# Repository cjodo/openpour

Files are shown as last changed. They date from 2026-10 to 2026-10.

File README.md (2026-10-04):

# OpenPour

An open-source automatic pour-over machine. It has a 3D-printed body and
commodity parts from the 3D-printer aisle. It's controlled from any phone or
laptop browser, with no app store and no cloud.

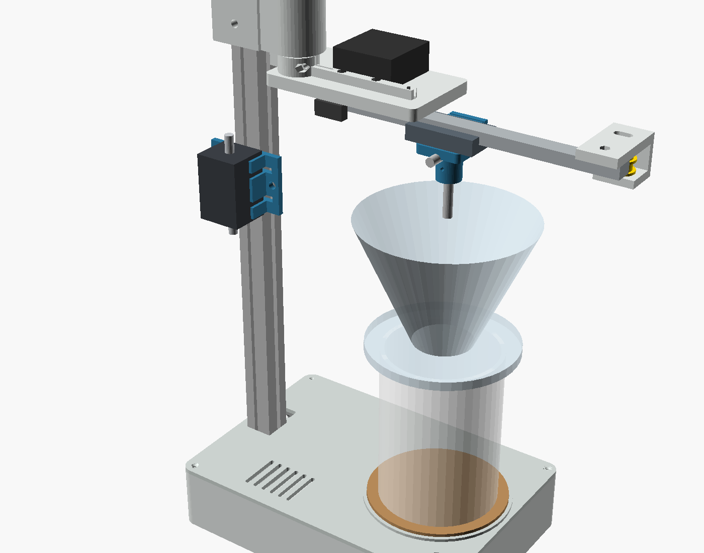
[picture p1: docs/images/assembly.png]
Assembly preview


- **Pours like a barista.** A two-axis polar arm traces centre, circle and
  spiral patterns over the dripper.
- **Pours by volume.** An inline flow meter counts every millilitre, and
  1 mL of water is 1 g, so each stage stops at its gram target whatever the
  pump does.
- **Configurable recipes.** Stages, water, flow rate, pattern, radius, speed
  and bloom/wait times are all editable in the app and stored on the machine.
- **Low voltage only.** You fill an insulated reservoir from your own
  kettle. The machine pumps, meters and measures temperature, but never
  heats water.
- **Parametric.** Set your cup and dripper heights in one OpenSCAD file and
  the column length, head position and parts follow.

## How it works

```
 reservoir ──tube──► peristaltic pump ──► flow meter ──► nozzle on carriage
 (hot water,                                  │            │  radial axis (belt, pancake NEMA17)
  DS18B20)                                    │   arm ─────┘  theta axis (direct-drive NEMA17)
                                              │    │
                                              │  dripper and cup on the base
                                              │
                ESP32 ◄────── pulses ─────────┘ ──Wi-Fi──► browser app (served by the ESP32)
```

The firmware converts each pattern from dripper-centred coordinates into arm
angle and carriage radius 100 times a second. Both steppers run in velocity
mode so the nozzle can follow spirals smoothly. The pump's speed is
feed-forward from its calibrated rate, trimmed by the measured flow, and cut
just early enough that the pump's coast-down lands on target.

## Repository

| Path | What |
|---|---|
| `hardware/cad/` | OpenSCAD model. `config.scad` holds every dimension; `make` exports STLs |
| `firmware/` | ESP32 firmware in Rust: `pourcore/` holds the hardware-independent logic, `esp32/` runs it on ESP-IDF, `sim/` runs it on a PC against simulated hardware |
| `web/` | The control app: TypeScript (`src/`) bundled with esbuild into `dist/`, which the firmware embeds at build time |
| `docs/` | [BOM](docs/BOM.md), [wiring](docs/wiring.md), [assembly](docs/assembly.md), [calibration](docs/calibration.md) |

## Build it

1. **Print.** In `hardware/cad`, edit `config.scad`, then run `make`, or
   open `openpour.scad` in OpenSCAD and choose a part. Print in PETG or ASA.
2. **Buy.** See the [bill of materials](docs/BOM.md). It comes to about
   US$170–210 (CA$240–300, €150–190).
3. **Wire.** See [wiring](docs/wiring.md).
4. **Flash.** Install [Node.js](https://nodejs.org) 18 or newer (the
   firmware build compiles the web app), and the Rust ESP32 toolchain once:
   ```sh
   cargo install espup ldproxy espflash
   espup install --targets esp32     # writes ~/export-esp.sh
   ```
   espflash 4.6 needs Rust 1.95 or newer; on an older Rust, install
   `espflash@4.5.0` instead.
   Then plug in the board and run:
   ```sh
   source ~/export-esp.sh
   cd firmware/esp32
   cargo run --release    # builds the web app and firmware, flashes, opens the monitor
   ```
   The first build downloads ESP-IDF, so it takes a while. The serial
   monitor shows the address to open. On Linux, add yourself to the group
   that owns `/dev/ttyUSB0` (`uucp` on Arch, `dialout` on Debian/Ubuntu).
5. **Calibrate.** Follow [calibration](docs/calibration.md). On first boot,
   join the `OpenPour-XXXX` Wi-Fi network (password `pourover`) and open
   http://192.168.4.1.

## Develop without hardware

### Host simulator (the real firmware logic)

`firmware/sim` runs the firmware's logic (`pourcore`: brewing, flow control,
motion, the flow meter, command handling) on your computer against simulated
hardware: stepper axes with endstop switches, a pump with ripple and
coast-down, and a flow meter whose real pulses-per-litre differs from the
default, so calibration matters as it does on a real machine. It serves the
built web app and the firmware's exact API.

```sh
cd web && npm ci && npm run watch      # rebuilds web/dist on save (or `npm run build` once)
cd firmware/sim && cargo run           # then open http://localhost:8080
```

- **Options:** `--speed 4` runs four times faster, `--lan` lets a phone on your
  network connect, and `--port`, `--data` and `--web` change the defaults.
  Settings and recipes persist in `firmware/sim/data/`.
- **Logging:** the firmware's log lines print in the terminal. Run with
  `RUST_LOG=debug` to also see the flow controller's internals.
- **`GET /api/sim`** shows what really happened, for example how much water
  reached the cup (`dispensedG`). Use it as the "real amount" when you
  calibrate the meter.
- **`POST /api/sim`** injects faults and drives the hardware, for example:

  ```sh
  curl -X POST localhost:8080/api/sim -d '{"faults":{"dry":true}}'
  ```

  - Faults: `dry`, `meterDead`, `radialEndstopStuck`, `thetaEndstopStuck`,
    `noProbe`.
  - Hardware: `trueGps` (pump rate), `truePpl` (meter pulses per litre),
    `tempC`, `{"press": "short"|"long"}` (the front button), and
    `{"resetDispensed": true}`.

### Wokwi (the real firmware on a simulated ESP32)

[Wokwi](https://wokwi.com) emulates the ESP32 itself, so it runs the actual
firmware image: ESP-IDF, Wi-Fi, the HTTP server and the drivers. Use it for
the code the host simulator can't reach. `firmware/wokwi/diagram.json` wires
up the board as `docs/wiring.md` describes, with two custom chips written in
Rust (`firmware/wokwi/chips`):

- **Pump + flow meter:** it reads the pump's PWM duty on GPIO 23 and sends
  pulses to GPIO 16 at a realistic rate.
- **Stepper axis + endstop** (one per axis): it counts STEP/DIR pulses and
  closes the endstop switch at the end of travel, so homing really runs.

Each chip has sliders for faults: dry pump, dead meter and a broken switch.
The DS18B20, the button and a pump LED are standard Wokwi parts.

```sh
firmware/wokwi/run.sh --timeout 60000     # builds if needed (--build to force), then runs wokwi-cli
```

`run.sh` takes the token from `WOKWI_CLI_TOKEN` or from `~/.wokwi/token` (a
bare token or a `NAME=token` line). It explains a missing or rejected token,
and passes any other options to `wokwi-cli`. `build.sh` builds the chips, the
firmware with `--features wokwi`, and a 4 MB flash image.

The `wokwi` feature makes the firmware join Wokwi's open `Wokwi-GUEST`
network instead of starting its own access point. In VS Code with the Wokwi
extension, open `firmware/wokwi/` and the web app is at
http://localhost:8180. The token is free from wokwi.com/dashboard/ci.

### Browser-only mock

```sh
cd web
npm ci
npm run dev
# open http://localhost:8000/?mock          (add &speed=4 to fast-forward)
```

`src/mock.ts` is a simplified machine written in TypeScript. It needs no Rust
toolchain, and edits to `src/` show up on reload. Because it's a separate
implementation, check behaviour against the host simulator. The protocol's
types live in `src/types.ts`. Before committing, run `npm run typecheck`
(`npm run build` also runs it). Neither simulator is part of the firmware
build.

## Firmware tests

Kinematics, pour patterns, flow control, flow-meter counting, motion control,
the brew state machine and command handling all live in `pourcore`, which
has no hardware dependencies. Its tests run on your computer, with a
simulated machine for the brew tests. The simulator's own tests brew through
the real homing sequence and flow meter, including fault cases:

```sh
cd firmware/pourcore && cargo test
cd firmware/sim && cargo test
```

## Recipe format

Recipes are stored on the machine as JSON. `water` is the amount added
in that stage, in grams.

```json
{
  "id": "v60-single",
  "name": "V60 single cup",
  "dose": 15,
  "minTemp": 92,
  "stages": [
    { "name": "Bloom", "water": 45, "flow": 4, "pattern": "spiral", "radius": 22, "rps": 1.2, "wait": 40 },
    { "name": "Pour 1", "water": 55, "flow": 4.5, "pattern": "spiral", "radius": 26, "rps": 1, "wait": 10 }
  ]
}
```

`pattern` is `center`, `circle` or `spiral`. `rps` is revolutions per
second around the dripper.

## API

| | |
|---|---|
| `GET /api/settings`, `POST /api/settings` | Machine settings (partial updates allowed) |
| `GET /api/recipes`, `POST /api/recipes` | The full recipe array |
| `ws://<host>/ws` | Status pushed 5× per second; send `{"cmd": "start", "recipe": "<id>"}`, `pause`, `resume`, `stop`, `home`, `park`, `center`, `jog`, `setCenter`, `release`, `prime`, `meterRun` (calibration dispense), `calMeter` (`{"ml": <measured>}`), `calPump` |

## Status

The firmware (Rust, on ESP-IDF) compiles and its core logic is unit-tested,
including simulated brews, but it hasn't run on real hardware yet. The app
runs against the simulator. The mechanical design is a first revision that hasn't
been printed yet. Expect to adjust clearances, switch positions and hole
sizes on the first build. Reports and fixes are welcome.

## Safety

Hot water burns. Keep the reservoir lid on and the machine on a stable
surface, and never run the pump without a cup under the nozzle. The firmware
stops if the flow meter sees no water, or if it counts more than the recipe
holds. It can't see what is in the cup, though, so it is not a substitute
for paying attention.

## License

MIT. See [LICENSE](LICENSE).

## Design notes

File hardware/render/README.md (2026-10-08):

# Renders

Scripts for picturing the assembled machine outside OpenSCAD. Generated files
go to `out/`, which git ignores. Add new render scripts here.

## The assembly as separate parts

```sh
hardware/render/export.sh                     # out/assembly/*.stl, ~15 s
hardware/render/export.sh -D 'arm_theta=-30' -D 'carriage_r=140' -o hardware/render/out/swung
```

This exports one STL per component, rendered in parallel. All the files
share the assembly's coordinates (millimetres, Z up), so they import already
in place, and each one can get its own material. Any `-D` option goes
straight to OpenSCAD:
- `arm_theta` (−78 to 25°) and `carriage_r` (66 to 175 mm) pose the arm;
- `show_cup=false` leaves out the mug and dripper;
- `$fn=128` gives rounder curves for close-ups.

The components are named by `component("...")` in
`hardware/cad/openpour.scad`. When you add a part to the assembly there, wrap
it the same way and add its name to the list in `export.sh`.

For a single merged STL instead (no separate materials, and touching parts
fuse together):

```sh
cd hardware/cad && openscad -D 'part="assembly"' -o assembly.stl openpour.scad
```

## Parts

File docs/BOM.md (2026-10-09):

# Bill of materials

Every purchased part is a commodity item from the 3D-printer, maker or
plumbing aisle. All of them are available from AliExpress, Amazon and most
maker shops. Prices are rough single-unit figures as a guide, not quotes.
CAD and EUR are converted from USD at 1 USD ≈ 1.42 CAD ≈ 0.89 EUR
(October 2026), so local prices and shipping will vary.

## Motion

| Qty | Part | Notes | ≈ USD | ≈ CAD | ≈ EUR |
|---|---|---|---|---|---|
| 1 | NEMA17 stepper, 40 mm body | Arm swing (theta), direct drive | 10 | 14 | 9 |
| 1 | NEMA17 "pancake" stepper, 20–23 mm body | Carriage (radial). Shaft ≥ 18 mm | 9 | 13 | 8 |
| 1 | MGN12H linear rail, 200 mm, with carriage | The arm itself | 12 | 17 | 11 |
| 1 | GT2 20T pulley, 5 mm bore, 6 mm belt | On the pancake motor, mounted hub-up | 1 | 1 | 1 |
| 1 | GT2 20T toothless idler, 5 mm bore | Arm tip | 1 | 1 | 1 |
| 1 | GT2 6 mm open belt, 1 m | ~520 mm used | 2 | 3 | 2 |
| 1 | Flexible shaft coupler, 5 mm to 8 mm | Theta motor to pivot shaft | 2 | 3 | 2 |
| 1 | 8 mm steel rod, 100 mm | Pivot shaft (linear rod offcut is fine) | 3 | 4 | 3 |
| 2 | 608ZZ bearing | Pivot | 1 | 1 | 1 |
| 1 | 8 mm shaft collar | Above the top bearing, carries the arm's weight | 1 | 1 | 1 |
| 1 | 2020 aluminium extrusion, 400 mm | Column. `column_len` in the CAD gives the exact length for your cups | 5 | 7 | 4 |
| 2 | Lever microswitch, KW11-3Z (20 × 10 mm) | Endstops | 1 | 1 | 1 |

## Water

| Qty | Part | Notes | ≈ USD | ≈ CAD | ≈ EUR |
|---|---|---|---|---|---|
| 1 | 12 V peristaltic pump, 300–400 mL/min | Kamoer KPHM400-style or equivalent. Peristaltic means only the tube touches water | 25–40 | 36–57 | 22–36 |
| 1.5 m | Food-grade silicone tubing to fit the pump, rated ≥ 100 °C | | 4 | 6 | 4 |
| 1 | ¼" (6 mm) 304 stainless 90° elbow hose barb | The nozzle. One leg is clamped vertically by the holder | 3 | 4 | 3 |
| 1 | Vacuum-insulated jug, 1–1.5 L, wide mouth | The reservoir. Fill it from your kettle | 15 | 21 | 13 |
| 1 | DS18B20 waterproof probe (stainless) + 4.7 kΩ resistor | Hangs in the reservoir | 2 | 3 | 2 |
| 1 | Hall-effect flow meter for hot drinks + 10 kΩ resistor | Measures the water, since 1 mL = 1 g. See below | 20–35 | 28–50 | 18–31 |
| 1 | Cork or silicone coaster, 95 mm | Sits in the lid's ring so hot cups never touch the print | 1 | 1 | 1 |

### Choosing the flow meter

The machine pours by volume, so the flow meter sets the accuracy.
- **Food-safe and rated for brewing-temperature water (≥ 90 °C).** Meters
  made for coffee machines, such as the Digmesa FHKSC family, are built for
  this.
- **Accurate from about 60 to 500 mL/min,** which covers recipes from 1 to
  8 g/s.
- **Pulse output with a known pulses-per-litre figure.** It's usually
  open-collector, powered from 5 V. The firmware's default is 1925 pulses/L;
  calibration measures yours.
- **Barbs that fit your tubing,** usually ¼" (6 mm).

Avoid the cheap YF-S401 / YF-S201 garden-style sensors. Most are rated to
about 80 °C, are not food-safe, and lose accuracy below about 300 mL/min.

## Electronics

| Qty | Part | Notes | ≈ USD | ≈ CAD | ≈ EUR |
|---|---|---|---|---|---|
| 1 | ESP32 DevKit V1 (ESP32-WROOM-32) | 30- or 38-pin. Not a WROVER board (GPIO 16) | 5 | 7 | 4 |
| 2 | TMC2209 StepStick driver | Standalone STEP/DIR, MS1 + MS2 high for 1/16 microstepping | 8 | 11 | 7 |
| 2 | StepStick carrier/expansion board | The small red boards with screw terminals and a 100 µF cap | 2 | 3 | 2 |
| 1 | Logic-level MOSFET module (AOD4184 / D4184 type) | Pump PWM | 1 | 1 | 1 |
| 1 | Schottky diode SS34 or 1N5819 | Across the pump motor (flyback) | 0.2 | 0.3 | 0.2 |
| 1 | Buck converter 12 V → 5 V (MP1584 or LM2596) | Powers the ESP32 via its 5 V/VIN pin | 1 | 1 | 1 |
| 1 | 12 V 5 A power supply, 5.5 × 2.1 mm plug | | 10 | 14 | 9 |
| 1 | Panel-mount DC jack, 5.5 × 2.1 mm (11–12 mm hole) | | 1 | 1 | 1 |
| 1 | 12 mm momentary push button | Start / pause / stop | 1 | 1 | 1 |
| 1 | 5 × 7 cm double-sided prototype board + female headers | Carries the ESP32 | 1 | 1 | 1 |
| – | Dupont/JST leads, 22 AWG wire for 12 V | | 3 | 4 | 3 |

## Fasteners

| Qty | Part | Where |
|---|---|---|
| ~30 | M3 screws 8–12 mm + nuts | Lid, rail, carriage, brackets, motors (from below through the motor plates) |
| 1 | M5 × 12 mm | Up through the base into the column (tap the extrusion's centre hole M5) |
| 4 | M5 × 10 mm + 4 drop-in T-nuts | Head clamp |
| 2 | M5 × 10 mm + 2 drop-in T-nuts | Pump bracket |
| 2 | M5 × 10 mm + 2 drop-in T-nuts | Flow meter clip |
| 2 | Cable ties, 3–4 mm wide | Flow meter to its clip |
| 1 | M5 × 40 mm + nut | Idler axle |
| 4 | 10 mm self-adhesive rubber feet | Base |

Expect about **US$185–235 / CA$260–330 / €165–210** total with the pump
and jug, less if you have printer leftovers. Filament for the printed parts
adds about US$11–15 / CA$16–21 / €10–13 (see [Filament](#filament)).

## Printed parts

Export with `make` in `hardware/cad` (or open `openpour.scad` and pick a
`part`). Print in PETG or ASA at 0.2 mm, 4 perimeters, 30 % infill.

| Part | Qty | ≈ g each | Orientation |
|---|---|---|---|
| base_tub | 1 | 245 | as exported (floor down) |
| base_lid | 1 | 120 | as exported |
| head | 1 | 80 | as exported (bearing pocket down) |
| arm_root | 1 | 50 | as exported (rail face down) |
| arm_tip | 1 | 12 | as exported |
| nozzle_holder | 1 | 12 | as exported. Supports under the belt clamp |
| switch_bracket | 2 | 2 | as exported |
| pump_bracket | 1 | 20 | as exported. Drill the slots to suit your pump |
| meter_clip | 1 | 12 | as exported (column plate down). Set `meter_body` in `config.scad` to your meter first |

### Filament

The parts weigh about **550 g** in PETG at the settings above. Allow about
**600 g** for supports, brims and purge, which is roughly 60 % of a 1 kg
spool. At US$18–25 per kg, the filament costs about
**US$11–15 / CA$16–21 / €10–13**. ASA weighs about 15 % less (it's less dense).

The weights are estimates from the CAD volumes, not slicer output, so your
slicer's figure may differ by 10–15 %. Most of the plastic is in the
thin-walled base tub and lid, which print nearly solid at any infill.

No printed part touches water or a hot cup. Water only touches the silicone
tube, the flow meter and the stainless nozzle, and the coaster isolates the
cup's heat.
PETG softens around 80 °C, which is why the coaster matters.

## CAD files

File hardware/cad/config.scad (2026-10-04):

// OpenPour: every dimension you might want to change lives here.
// Units: mm. Origin: the arm pivot axis at table level. +X points from the
// pivot to the dripper (towards the user), +Z is up.

/* [Your cups and dripper] */
cup_height = 110;        // tallest mug or server you'll brew into
dripper_height = 90;     // dripper body including its base
nozzle_clearance = 20;   // gap between dripper rim and nozzle tip

/* [Layout] */
dripper_offset = 110;    // pivot axis to dripper centre (firmware: centerR)
column_x = -35;          // 2020 column centre
base_back = -52;         // base rear edge
base_front = 163;        // base front edge
base_width = 150;

/* [Print settings] */
wall = 2.4;
clearance = 0.25;        // added to holes and sockets; raise for loose printers
$fn = 48;

/* [Base] */
floor_t = 3;
tub_height = 43;         // floor bottom to lid underside
lid_t = 3;
corner_boss_d = 9;
screw_m3_tap = 2.6;      // self-tapping into plastic; 4.0 for heat-set inserts
screw_m3_clear = 3.4;
screw_m4_clear = 4.4;
screw_m5_clear = 5.4;

/* [Cup rest] */
coaster_d = 95;              // cork/silicone coaster: printed parts must not touch hot cups
coaster_t = 4;
coaster_ring_h = 2;          // locating ring on the lid keeps the coaster under the dripper

/* [Flow meter: measure yours] */
meter_body = [45, 30, 28];   // length along the flow x width x height, without the barbs
meter_barb_len = 12;         // each end

/* [Column, 2020 extrusion] */
ext = 20;
column_socket_depth = 35;   // leaves solid plastic under the column for its M5 bolt

/* [Head: theta motor + pivot] */
nema = 42.3;
nema_hole_spacing = 31;
nema_boss_d = 22.5;          // flange pilot
coupler_d = 20;              // 5 mm to 8 mm flexible coupler
coupler_len = 25;
collar_t = 10;               // 8 mm shaft collar above the top bearing
bearing_od = 22;             // 608
bearing_t = 7;
head_h = 65;
head_gap = 2;                // between head and arm hub

/* [Arm] */
// Nothing on the arm may reach further than ~22 mm behind the pivot, or it
// hits the column when the arm swings.
shaft_d = 8;
hub_d = 26;
hub_h = 20;
finger_r = 21;               // theta endstop finger, points at the column at theta = 0
beam_t = 8;
beam_back = -15;
beam_front = 95;
beam_y = [-16, 46];          // beam spans the rail (y = 0) and the motor/belt side
rail_len = 200;
rail_start = 20;             // rail end nearest the pivot
rail_w = 12;
rail_h = 8;
rail_hole_pitch = 25;
rail_hole_first = 12.5;
radial_motor_x = 45;         // pancake NEMA17 on top of the beam, shaft down
radial_motor_len = 23;       // pancake NEMA17 body
radial_motor_pocket = 4;     // motor face sits this far into the beam (pulley mounted hub-up)
belt_y = 24;                 // belt loop centre line, beside the carriage
pulley_z = [-16, -2];        // pulley/idler band below the beam
pulley_pitch_r = 6.37;       // GT2 20T

/* [Carriage + nozzle (MGN12H)] */
carriage_w = 27;
carriage_len = 45.4;
carriage_h = 13;             // rail mount face to carriage face
carriage_hole_spacing = 20;  // 20 x 20 M3 pattern
nozzle_d = 8;                // leg of a 1/4" stainless elbow barb
nozzle_drop = 25;            // nozzle tip below the holder plate
holder_t = 6;

/* [Endstops: KW11-3Z style lever switch, 20 x 10 x 6.4] */
switch_hole_spacing = 9.5;
switch_hole_d = 2.2;

// ---------------------------------------------------------------- derived
lid_top = tub_height + lid_t;
cup_base_z = lid_top + coaster_t;
nozzle_tip_z = cup_base_z + cup_height + dripper_height + nozzle_clearance;
beam_bottom_z = nozzle_tip_z + nozzle_drop + holder_t + carriage_h;
head_bottom_z = beam_bottom_z + hub_h + head_gap;
head_top_z = head_bottom_z + head_h;
column_bottom_z = tub_height - column_socket_depth;
column_len = ceil((head_top_z - column_bottom_z) / 10) * 10;  // cut your 2020 to this

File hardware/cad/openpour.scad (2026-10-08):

// OpenPour: open the file in OpenSCAD for the assembly preview, or export one
// print-ready part at a time:
//   openscad -D 'part="head"' -o stl/head.stl openpour.scad
// (`make` in this folder exports all of them.)

include <config.scad>
use <vitamins.scad>
include <parts.scad>

/* [View] */
part = "assembly";  // [assembly, base_tub, base_lid, head, arm_root, arm_tip, nozzle_holder, switch_bracket, pump_bracket, meter_clip]
arm_theta = 0;      // [-78:1:25]
carriage_r = 110;   // [66:1:175]
show_cup = true;
component = "all";  // one piece of the assembly, for hardware/render/export.sh

echo(str("Cut the 2020 column to ", column_len, " mm. Nozzle tip at ", nozzle_tip_z, " mm above the table."));

if (part == "assembly") assembly();
else print_part(part);

module print_part(name) {
  if (name == "base_tub") base_tub();
  if (name == "base_lid") translate([0, 0, -tub_height]) base_lid();
  if (name == "head") translate([0, 0, -head_bottom_z]) head();
  if (name == "arm_root") arm_root();
  if (name == "arm_tip") translate([0, 0, 6]) rotate([180, 0, 0]) arm_tip();
  if (name == "nozzle_holder")
    translate([0, 0, carriage_h + holder_t]) nozzle_holder();
  if (name == "switch_bracket") switch_bracket();
  if (name == "pump_bracket") pump_bracket();
  if (name == "meter_clip") rotate([90, 0, 0]) meter_clip();  // plate on the bed
}

// Renders its children only when `component` selects them (or is "all"), so
// hardware/render/export.sh can export the assembly one piece at a time.
module component(name) {
  if (component == "all" || component == name) children();
}

module arm_assembly() {
  component("arm") color("#e2e6e4") arm_root();
  component("arm") color("#e2e6e4") arm_tip();
  component("rail") translate([0, 0, -rail_h]) translate([rail_start, 0, 0]) mgn12_rail(rail_len);
  // face down in its pocket, shaft through the beam
  component("motor_radial")
    translate([radial_motor_x, belt_y, beam_t - radial_motor_pocket]) mirror([0, 0, 1]) nema17(radial_motor_len, 20);
  component("pulleys") {
    translate([radial_motor_x, belt_y, pulley_z[0]]) gt2_pulley();
    translate([rail_start + rail_len - 12, belt_y, pulley_z[0]]) gt2_pulley();
  }
  translate([carriage_r, 0, 0]) {
    component("carriage") translate([0, 0, -carriage_h]) mgn12h_carriage();
    component("nozzle_holder") color("#2e7da6") nozzle_holder();
    component("nozzle") translate([0, 0, -carriage_h - holder_t]) elbow_barb(nozzle_drop + 18);
  }
  component("switch") color("#444") translate([radial_switch_screws[0] - 6, -14, -12]) cube([20, 6.4, 10]);
}

module assembly() {
  component("base_tub") color("#e2e6e4") base_tub();
  component("base_lid") color("#cfd6d3") base_lid();
  component("coaster") translate([dripper_offset, 0, lid_top]) coaster(coaster_d, coaster_t);

  component("column") translate([column_x, 0, column_bottom_z]) ext2020(column_len);
  // flow meter on the column's side face, between the pump and the nozzle
  meter_z = head_bottom_z - 110;  // well below the arm and its pulleys
  translate([column_x, -ext / 2, meter_z]) rotate([0, 0, 180]) translate([-(meter_body[1] + 2 * wall + 20) / 2, 0, 0]) {
    component("meter_clip") color("#2e7da6") meter_clip();
    component("flow_meter") translate([10 + wall + meter_body[1] / 2, 4 + meter_body[2] / 2, 20 - meter_body[0] / 2])
      rotate([0, 0, 90]) rotate([0, -90, 0]) flow_meter(meter_body, meter_barb_len);
  }
  component("head") color("#e2e6e4") head();
  component("motor_theta") translate([0, 0, head_top_z]) mirror([0, 0, 1]) nema17();  // face down on the head
  component("bearings") for (z = [head_top_z - coupler_len - collar_t - 3 - bearing_t, head_bottom_z])
    translate([0, 0, z]) bearing608();
  component("shaft") color("silver") translate([0, 0, beam_bottom_z])
    cylinder(d = shaft_d, h = head_top_z - coupler_len / 2 - beam_bottom_z);

  translate([0, 0, beam_bottom_z]) rotate(arm_theta) arm_assembly();

  if (show_cup) translate([dripper_offset, 0, cup_base_z]) {
    component("mug") mug(cup_height);
    component("dripper") translate([0, 0, cup_height]) dripper(dripper_height);
  }
}

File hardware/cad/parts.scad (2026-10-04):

// Printed parts. Modules are drawn in assembly position; openpour.scad
// re-orients each one for printing.
//
// Arm parts use arm-local coordinates: origin on the pivot axis at the
// underside of the beam (where the rail mounts), +X along the arm.

include <config.scad>

e = 0.01;
C = clearance;

module rounded_box(size, r) {
  hull() for (x = [r, size[0] - r], y = [r, size[1] - r])
    translate([x, y, 0]) cylinder(r = r, h = size[2]);
}

module counterbored(d, head_d, head_h, len) {
  // hole along +Z from z=0, head recess at the bottom
  translate([0, 0, -e]) cylinder(d = d, h = len + 2 * e);
  translate([0, 0, -e]) cylinder(d = head_d, h = head_h + e);
}

// ------------------------------------------------------------------ base

base_len = base_front - base_back;
corner_inset = 6.5;
function corner_positions() = [
  for (x = [base_back + corner_inset, base_front - corner_inset],
       y = [-base_width / 2 + corner_inset, base_width / 2 - corner_inset]) [x, y]
];

// 50 x 70 mm double-sided prototype board for the ESP32 (M2 holes).
proto_board_origin = [-17, -35];
proto_board_holes = [[2, 2], [46 + 2, 2], [2, 66 + 2], [46 + 2, 66 + 2]];
button_pos = [base_front - 18, -base_width / 2 + 18];

module base_tub() {
  sock = ext + 10;
  difference() {
    union() {
      difference() {
        translate([base_back, -base_width / 2, 0]) rounded_box([base_len, base_width, tub_height], 8);
        translate([base_back + wall, -base_width / 2 + wall, floor_t])
          rounded_box([base_len - 2 * wall, base_width - 2 * wall, tub_height], 8 - wall);
      }
      for (p = corner_positions()) translate(p) cylinder(d = corner_boss_d, h = tub_height);
      // column socket
      translate([column_x - sock / 2, -sock / 2, 0]) cube([sock, sock, tub_height]);
      // proto board standoffs
      for (h = proto_board_holes) translate(proto_board_origin + h) cylinder(d = 6, h = floor_t + 5);
    }
    for (p = corner_positions()) translate([p[0], p[1], floor_t]) cylinder(d = screw_m3_tap, h = tub_height);
    // column pocket + M5 bolt up into the tapped extrusion end
    translate([column_x - ext / 2 - C, -ext / 2 - C, column_bottom_z]) cube([ext + 2 * C, ext + 2 * C, tub_height]);
    translate([column_x, 0, 0]) counterbored(screw_m5_clear, 10, 4, column_bottom_z);
    for (h = proto_board_holes) translate([proto_board_origin[0] + h[0], proto_board_origin[1] + h[1], 1]) cylinder(d = 1.7, h = 10);
    // rear wall: DC barrel jack (panel mount) and ESP32 USB access
    translate([base_back - 1, 40, 20]) rotate([0, 90, 0]) cylinder(d = 11.5 + C, h = wall + 2);
    translate([base_back - 1, -12, floor_t + 6]) cube([wall + 2, 14, 9]);
    // rubber foot recesses
    for (p = corner_positions()) translate([p[0], p[1], -e]) cylinder(d = 10.5, h = 1);
  }
}

module base_lid() {
  difference() {
    union() {
      translate([base_back, -base_width / 2, tub_height]) rounded_box([base_len, base_width, lid_t], 8);
      // coaster locating ring, centred under the dripper
      translate([dripper_offset, 0, lid_top - e]) difference() {
        cylinder(d = coaster_d + 2 * C + 2 * wall, h = coaster_ring_h + e);
        translate([0, 0, -1]) cylinder(d = coaster_d + 2 * C, h = coaster_ring_h + 2);
      }
    }
    for (p = corner_positions()) translate([p[0], p[1], tub_height - e]) {
      cylinder(d = screw_m3_clear, h = lid_t + 1);
      translate([0, 0, lid_t - 1.8]) cylinder(d1 = screw_m3_clear, d2 = 6.5, h = 1.8 + e);
    }
    translate([column_x - ext / 2 - C, -ext / 2 - C, tub_height - 1]) cube([ext + 2 * C, ext + 2 * C, lid_t + 2]);
    // momentary button (12 mm)
    translate([button_pos[0], button_pos[1], tub_height - 1]) cylinder(d = 12 + C, h = lid_t + 2);
    // cable pass-through beside the column: motors, endstops, pump, probe, flow meter
    translate([column_x - 8, ext / 2 + 5, tub_height - 1]) rounded_box([16, 10, lid_t + 2], 2);
    // vents over the stepper drivers
    for (i = [0 : 5]) translate([-5 + i * 7, -base_width / 2 + 12, tub_height - 1]) rounded_box([3, 30, lid_t + 2], 1.4);
  }
}

// ------------------------------------------------------------------ head

head_r = bearing_od / 2 + 6;

module head() {
  hb = head_bottom_z;
  ht = head_top_z;
  blk = ext + 16;
  cavity = coupler_len + collar_t + 3;
  difference() {
    union() {
      translate([column_x - blk / 2, -blk / 2, hb]) cube([blk, blk, head_h]);
      hull() {
        translate([column_x, -14, hb]) cube([e, 28, head_h]);
        translate([0, 0, hb]) cylinder(r = head_r, h = head_h);
      }
      translate([-nema / 2, -nema / 2, ht - 6]) cube([nema, nema, 6]);
    }
    // column bore and clamp screws into T-nuts on both side slots
    translate([column_x - ext / 2 - C, -ext / 2 - C, hb - 1]) cube([ext + 2 * C, ext + 2 * C, head_h + 2]);
    for (z = [hb + 14, ht - 14], s = [-1, 1])
      translate([column_x, s * (ext / 2 + 8 + 1), z]) rotate([90, 0, 0]) {
        cylinder(d = screw_m5_clear, h = 20, center = true);
        translate([0, 0, s > 0 ? -12 : 4]) cylinder(d = 10, h = 8);
      }
    // motor: pilot, coupler + collar cavity, 4 screws from below
    translate([0, 0, ht - cavity]) cylinder(d = coupler_d + 4, h = cavity + 1);
    for (x = [-1, 1], y = [-1, 1]) translate([x * nema_hole_spacing / 2, y * nema_hole_spacing / 2, ht - 7])
      cylinder(d = screw_m3_clear, h = 8);
    // bearings: top one under the cavity, bottom one from below
    translate([0, 0, ht - cavity - bearing_t]) cylinder(d = bearing_od + C, h = bearing_t + e);
    translate([0, 0, hb - e]) cylinder(d = bearing_od + C, h = bearing_t + e);
    translate([0, 0, hb]) cylinder(d = 16, h = head_h);
    // theta switch mount (two M3 pilots on the underside)
    for (p = theta_switch_mount_holes()) translate([p[0], p[1], hb - e]) cylinder(d = screw_m3_tap, h = 10);
  }
}

// The finger on the hub sweeps a circle of radius finger_r. The switch sits on
// that circle where the finger arrives at theta = thetaHomeDeg.
theta_home = -75;
function theta_switch_angle() = 180 + theta_home - 8;
function theta_switch_mount_holes() = [
  for (a = [theta_switch_angle() - 14, theta_switch_angle() + 2]) [ (head_r - 3) * cos(a), (head_r - 3) * sin(a) ]
];

// ------------------------------------------------------------------ arm

// The belt clamp must stay clear of the radial pulley, so the carriage homes
// at r ~ 66 mm (firmware radialHomeMm) against a switch under the beam.
radial_switch_screws = [28, 38];

function rail_holes() = [for (x = [rail_hole_first : rail_hole_pitch : rail_len]) rail_start + x];

module arm_root() {
  beam_y_len = beam_y[1] - beam_y[0];
  difference() {
    union() {
      translate([beam_back, beam_y[0], 0]) rounded_box([beam_front - beam_back, beam_y_len, beam_t], 4);
      cylinder(d = hub_d, h = hub_h);
      // endstop finger, pointing back at the column when theta = 0
      hull() {
        translate([-hub_d / 2 + 2, -3, beam_t]) cube([1, 6, hub_h - beam_t - 4]);
        translate([-finger_r, -2, beam_t]) cube([2, 4, hub_h - beam_t - 4]);
      }
      // stiffening rib along the rail line
      translate([hub_d / 2 - 2, -4, beam_t - e]) cube([beam_front - hub_d / 2 - 2 - 6, 6, 6]);
    }
    // shaft bore + clamp slit + clamp screw
    translate([0, 0, -1]) cylinder(d = shaft_d + C, h = hub_h + 2);
    translate([0, -0.75, beam_t]) cube([hub_d, 1.5, hub_h]);
    translate([hub_d / 2 - 4, 0, beam_t + (hub_h - beam_t) / 2]) rotate([90, 0, 0]) {
      cylinder(d = screw_m3_clear, h = hub_d, center = true);
      translate([0, 0, 5]) cylinder(d = 6.4, h = 10, $fn = 6);
    }
    // rail screws from below into nuts on top
    for (x = rail_holes()) if (x < beam_front - 4) translate([x, 0, -e]) {
      cylinder(d = screw_m3_clear, h = beam_t + 10);
      translate([0, 0, beam_t - 2.5]) cylinder(d = 6.4, h = 10, $fn = 6);
    }
    // radial motor: pocket, shaft, pilot, screws
    translate([radial_motor_x, belt_y, 0]) {
      translate([-nema / 2 - C, -nema / 2 - C, beam_t - radial_motor_pocket]) cube([nema + 2 * C, nema + 2 * C, 20]);
      translate([0, 0, -1]) cylinder(d = nema_boss_d + 1, h = beam_t + 2);
      for (x = [-1, 1], y = [-1, 1]) translate([x * nema_hole_spacing / 2, y * nema_hole_spacing / 2, -1]) {
        cylinder(d = screw_m3_clear, h = beam_t + 2);
        translate([0, 0, -e]) cylinder(d = 6, h = 1 + 1.5);
      }
    }
    // radial endstop bracket screws
    for (x = radial_switch_screws) translate([x, -12, -e]) cylinder(d = screw_m3_tap, h = 6);
  }
}
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

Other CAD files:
hardware/cad/vitamins.scad

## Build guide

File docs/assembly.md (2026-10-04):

# Assembly

Assembly preview

Before you start, set your cup and dripper heights in
`hardware/cad/config.scad`. `column_len` (printed in the OpenSCAD console as
a derived value) is the length to cut the 2020 extrusion to. A 400 mm stock
length covers mugs up to ~120 mm under a V60.

## Base

1. Press rubber feet into the four recesses under `base_tub`.
2. Tap the 2020 extrusion's centre hole M5 at one end. Push it into the
   socket and bolt it from underneath with an M5 × 12.
3. Fit the ESP32 prototype board on the standoffs, the stepper carriers on
   either side, and the MOSFET module and buck converter in front of them.
   Fix them with double-sided foam tape. Fit the DC jack to the rear wall.
   See [wiring.md](wiring.md).
4. Fit the button to the lid, route the cable bundle through the slot beside
   the column, and screw the lid on (4 × M3, countersunk).
5. Drop the coaster into the ring on the lid.

## Head and arm

1. Press the two 608 bearings into the head: one from below, and one into
   the pocket under the coupler cavity.
2. Bolt the 40 mm NEMA17 face-down on top of the head (4 × M3 from below).
   Fit the coupler on its shaft.
3. Slide the 8 mm shaft up through both bearings into the coupler. Put the
   collar on the shaft above the top bearing first, then tighten the
   coupler. The collar takes the arm's weight. Snug it so the shaft has no
   end-play but still turns freely.
4. Slide the head down the column on four T-nuts. Set its height so the
   nozzle ends up ~20 mm above your dripper rim, then tighten.
5. Fix the rail to the underside of `arm_root` (M3 up through the rail into
   nuts in the hex traps). Bolt `arm_tip` to the last rail hole.
6. Bolt the pancake motor into its pocket and fit the GT2 pulley hub-up
   below the beam. Fit the idler in the arm tip slot on an M5 × 40.
7. Clamp the arm's hub onto the shaft below the head with the M3 clamp
   screw.
8. Bolt `nozzle_holder` under the carriage (4 × M3). Loop the belt around
   the pulley and idler, tuck both ends into the holder's slot, pinch them
   with the M3, and tension by sliding the idler.
9. Fit one `switch_bracket` under the beam (radial endstop) so the carriage
   presses the lever about 23 mm before its centre reaches 66 mm from the
   pivot. Fit the other under the head (theta endstop) so the hub's finger
   presses it as the arm swings to about −75°. Fine-tune the exact numbers
   with **Arm angle at endstop** and **Carriage radius at endstop** in
   Advanced settings.

## Water

1. Bolt the pump bracket to the column with two T-nuts, then fit the pump.
2. Bolt `meter_clip` to the column's side face, above the pump and well below
   the arm, with two T-nuts. Cable-tie the flow meter into it with its barbs
   vertical and its arrow pointing **up**. Water flowing upward through the
   meter pushes the air out, so it stays full and counts accurately.
3. Push the stainless elbow's vertical leg into the nozzle holder so it pokes
   out ~25 mm below, then pinch it.
4. Run silicone tube from the bottom of the reservoir (weight the end with a
   stainless washer) through the pump, up through the meter, and on to the
   elbow. Keep the tube after the meter short. Leave a loose loop at the arm
   so it can swing.
5. Hang the DS18B20 probe in the reservoir.

Then work through [calibration.md](calibration.md).

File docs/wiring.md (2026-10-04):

# Wiring

Everything runs at 12 V or below. There is no mains voltage inside the
machine. The power brick is the only mains part, and it is off-the-shelf.

## Power

```
12 V brick ── DC jack ──┬── stepper carrier (theta)  VMOT
                        ├── stepper carrier (radial) VMOT
                        ├── pump (+) ──── pump (−) ── MOSFET module OUT−
                        │                 (SS34 across the pump, stripe to +)
                        ├── MOSFET module VIN+
                        └── buck converter IN ── 5 V OUT ── ESP32 5V/VIN
GND is common to everything, including the ESP32.
```

Set the buck converter to 5.0 V **before** connecting the ESP32.

## ESP32 pin map

The pin map is defined at the top of `firmware/esp32/src/main.rs`.

| ESP32 GPIO | Connects to | Notes |
|---|---|---|
| 26 | Theta driver STEP | |
| 25 | Theta driver DIR | |
| 33 | Radial driver STEP | |
| 32 | Radial driver DIR | |
| 27 | Both drivers EN | Active low, shared |
| 18 | Theta endstop | Switch COM to GND, NO to the pin (internal pull-up) |
| 19 | Radial endstop | Switch COM to GND, NO to the pin |
| 16 | Flow meter pulse output | 10 kΩ from the pin to 3V3. WROOM modules only, since WROVER uses 16 for PSRAM |
| 23 | MOSFET module PWM/SIG | |
| 4 | DS18B20 data | 4.7 kΩ from data to 3V3 |
| 13 | Push button | Other leg to GND |
| 2 | On-board LED | Status |

Power the DS18B20 from **3V3**, not 5 V, so its output is safe for the
ESP32. The flow meter can run from 5 V because its output is open-collector.
Pull that output up to **3V3 only**. If your meter has its own pull-up to its
supply, power it from 3V3 if the datasheet allows, or add a divider
(10 kΩ / 20 kΩ) so the pin never sees 5 V.

## Stepper drivers (TMC2209, standalone)

- Microstepping: MS1 **high**, MS2 **high** gives 1/16, which the firmware
  defaults assume. On carrier boards with three DIP switches, MS3 has no
  effect on a TMC2209, but check your driver's pinout. Some variants route
  PDN/UART to that pin.
- Motor current: set Vref for about 0.6 A RMS on the 40 mm motor and 0.4 A on the
  pancake. Most TMC2209 StepSticks use Vref ≈ I<sub>RMS</sub> × 1.41, but
  confirm against your board's documentation.
- Pair motor coils with a multimeter (continuity within a coil). If an axis
  runs backwards, tick **Reverse … direction** in the app's Advanced settings
  instead of rewiring.

## Flow meter

| Meter wire (typical) | Connects to |
|---|---|
| Red | 5 V |
| Black | GND |
| White, yellow or blue (signal) | GPIO 16, with 10 kΩ to 3V3 |

Wire colours vary, so check your meter's datasheet. The meter goes in the
tube between the pump and the nozzle, with its arrow pointing in the
direction of flow.

## Cable routing

Motor, endstop, pump, probe and flow meter cables leave the base through the slot beside
the column. Bundle them up the column with spiral wrap and leave a loose loop
to the arm so it can swing from −78° to +25°. The pump tube follows the same
path, through the flow meter, to the nozzle elbow.

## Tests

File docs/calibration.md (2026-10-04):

# First run and calibration

Everything here is done from the **Machine** tab of the app. Values are saved
on the machine and survive firmware updates.

## 1. Connect

On first boot the machine starts its own Wi-Fi network, **OpenPour-XXXX**,
with the password `pourover`. Join it and open http://192.168.4.1. Under
**Wi-Fi**, enter your home network and save. The machine restarts and is
then reachable at http://openpour.local. On some Android devices `.local`
names don't resolve, so use the IP address shown in the serial monitor or
your router's client list.

Add the page to your home screen to use it like an app.

## 2. Check directions and endstops

1. Press **Home**. The carriage should travel toward the pivot and stop on
   its switch, then the arm should swing toward its switch.
   - If an axis moves the wrong way, press **Motors off**, open
     **Advanced**, tick the matching **Reverse … direction** box, save, and
     home again.
   - If a switch never triggers, homing stops after 20 s with an error.
2. The arm then parks out of the way of the dripper.

## 3. Set the dripper centre

Put your cup and dripper on the coaster. Press **Go to centre**, then use the jog
pad until the nozzle sits over the middle of the dripper. Use **Fine** for
the last millimetres. Press **Save as centre**. Every pour pattern is drawn
around this point, so it absorbs any slop in the printed parts.

## 4. Prime

Fill the reservoir with hot water and put a cup under the nozzle. Press
**Prime 3 s** a few times until water flows steadily from the nozzle, with
no air bubbles in the tube.

The machine measures water as it passes the flow meter, so the tube between
the meter and the nozzle must already be full. Prime again whenever the
tube has drained, for example after refilling an empty reservoir.

## 5. Calibrate the flow meter

The meter's datasheet value is only a starting point. Each meter, and how
it's mounted, varies by a few percent.

1. Put an empty jug, or a mug on a kitchen scale (tared), under the nozzle.
2. Press **Dispense ~200 ml**. The machine homes, centres, and pumps until
   the meter has counted about 200 ml.
3. Measure what came out. On a kitchen scale, 1 g = 1 ml. Enter it under
   **Real amount** and press **Calibrate meter**.

Repeat once to check. The counted and real amounts should now agree to
within a couple of percent. Use hot water, as it would be when brewing.

## 6. Calibrate the pump

Empty the cup, put it back under the nozzle and press **Calibrate pump**.
The machine runs the pump flat out for 10 s and stores the rate the meter
measured. That rate is used to plan every pour.

## 7. Brew

On the **Brew** tab, choose a recipe and press **Start brew**, or press the
button on the base to brew the last recipe again. A short press pauses or
resumes, and a long press stops.

## Tuning notes

| Symptom | Setting (Advanced) |
|---|---|
| Overshoots each stage target | Raise **Pour stop lead time** |
| Stops short of each target | Lower **Pour stop lead time** |
| Cup holds more or less than the recipe | Re-run the flow meter calibration, and prime first |
| Pump stalls at slow flow rates | Raise **Pump minimum power** |
| Pattern looks small or large | Re-check **Carriage steps per mm** (80 for GT2 20T at 1/16) |
| Arm hits something at the end of travel | Narrow the arm/carriage min/max limits |

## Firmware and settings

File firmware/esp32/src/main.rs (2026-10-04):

//! OpenPour firmware: automated pour-over on an ESP32.
//! See ../../README.md for the hardware and ../../docs for wiring and
//! calibration. The machine logic lives in ../pourcore; this crate connects
//! it to the hardware.
//!
//! Pins (ESP32 DevKit V1, ESP32-WROOM-32; see docs/wiring.md). GPIO 16 is
//! free on WROOM modules; on WROVER (PSRAM) boards move the flow meter.
//!   theta stepper   STEP 26, DIR 25
//!   radial stepper  STEP 33, DIR 32
//!   stepper enable  27 (shared by both drivers, active low)
//!   endstops        theta 18, radial 19 (normally open to GND)
//!   flow meter      16 (pulse output, pulled up to 3V3)
//!   pump PWM        23 (gate of the MOSFET module)
//!   DS18B20         4 (4.7 kΩ pull-up to 3V3)
//!   button          13 (momentary to GND)
//!   status LED      2 (on-board)

mod ds18b20;
mod flowmeter;
mod net;
mod pump;
mod stepper;
mod storage;
mod web;

use esp_idf_svc::eventloop::EspSystemEventLoop;
use esp_idf_svc::hal::delay::FreeRtos;
use esp_idf_svc::hal::gpio::{Input, PinDriver, Pull};
use esp_idf_svc::hal::ledc::{config::TimerConfig, LedcDriver, LedcTimerDriver, Resolution};
use esp_idf_svc::hal::peripherals::Peripherals;
use esp_idf_svc::hal::reset;
use esp_idf_svc::hal::units::Hertz;
use esp_idf_svc::log::EspLogger;
use esp_idf_svc::nvs::EspDefaultNvsPartition;
use esp_idf_svc::sys::esp_timer_get_time;
use pourcore::app::{self, Button, Effect};
use pourcore::brew::Brew;
use pourcore::machine::{Machine, MotionCmd};
use pourcore::meter::FlowMeter;
use pourcore::motion::{Endstops, Motion};
use pourcore::nozzle;
use pourcore::recipes::{self, Recipe};
use pourcore::settings::Settings;
use serde_json::Value;

use crate::ds18b20::Ds18b20;
use crate::flowmeter::PulseCounter;
use crate::net::Net;
use crate::pump::Pump;
use crate::stepper::Stepper;

const STATUS_PERIOD_MS: u32 = 100;
const REBOOT_DELAY_MS: u32 = 1500;
/// A loop iteration longer than this is logged: it delays motion and flow control.
const LOOP_STALL_MS: u32 = 50;

fn millis() -> u32 {
    (unsafe { esp_timer_get_time() } / 1000) as u32
}

type Enable = Box<dyn FnMut(bool)>;

/// Every device behind the brew logic.
struct Devices {
    settings: Settings,
    net: Net,
    pulses: PulseCounter<'static>,
    meter: FlowMeter,
    thermo: Ds18b20<'static>,
    pump: Pump<'static>,
    motion: Motion<Stepper, Enable>,
    theta_endstop: PinDriver<'static, Input>,
    radial_endstop: PinDriver<'static, Input>,
}

impl Devices {
    fn update(&mut self, now: u32) {
        self.meter.on_count(self.pulses.total(), now, self.settings.flow_pulses_per_litre);
        self.thermo.update(now);
        self.pump.update(now);
        let end = Endstops { radial: self.radial_endstop.is_low(), theta: self.theta_endstop.is_low() };
        self.motion.update(now, &self.settings, end);
    }
}

impl Machine for Devices {
    fn now_ms(&self) -> u32 {
        millis()
    }

    fn settings(&self) -> &Settings {
        &self.settings
    }

    fn settings_mut(&mut self) -> &mut Settings {
        &mut self.settings
    }

    fn save_settings(&mut self) {
        stepper::set_inverted(self.settings.invert_theta, self.settings.invert_radial);
        if !storage::save_settings(&self.settings) {
            log::error!("could not save settings");
        }
        self.net.publish_settings(&self.settings);
    }

    fn load_recipe(&mut self, id: &str) -> Option<Recipe> {
        recipes::find(&storage::read_recipes()?, id)
    }

    fn first_recipe_id(&mut self) -> Option<String> {
        recipes::first_id(&storage::read_recipes()?)
    }

    fn save_recipes(&mut self, r: &Value) -> bool {
        storage::save_recipes(r)
    }

    fn grams(&self) -> f32 {
        self.meter.grams()
    }

    fn flow_gps(&self) -> f32 {
        self.meter.flow_gps()
    }

    fn flow_valid(&self) -> bool {
        self.meter.flow_valid()
    }

    fn meter_pulses(&self) -> u32 {
        self.meter.pulses()
    }

    fn reset_poured(&mut self) {
        self.meter.reset();
    }

    fn temp_c(&self) -> Option<f32> {
        self.thermo.celsius()
    }

    fn pump_set(&mut self, duty: f32) {
        self.pump.set(duty);
    }

    fn pump_run_for(&mut self, duty: f32, ms: u32) {
        self.pump.run_for(duty, ms, millis());
    }

    fn pump_duty(&self) -> f32 {
        self.pump.duty()
    }

    fn motion(&mut self, cmd: MotionCmd) {
        let s = &self.settings;
        let m = &mut self.motion;
        match cmd {
            MotionCmd::Home => m.home(millis(), s),
            MotionCmd::Hold => m.hold(s),
            MotionCmd::Park => m.park(s),
            MotionCmd::MoveToBed(p) => m.move_to_bed(p, s),
            MotionCmd::Follow(p) => m.follow(p, millis()),
            MotionCmd::Jog { dr, dtheta } => m.jog(dr, dtheta, s),
            MotionCmd::Release => m.release(),
            MotionCmd::SetCentreHere => {
                let p = m.centre_here(s);
                self.settings.center_r = p.r;
                self.settings.center_theta_deg = p.theta_deg;
                self.save_settings();
            }
        }
    }

    fn homed(&self) -> bool {
        self.motion.homed()
    }

    fn homing_failed(&self) -> bool {
        self.motion.homing_failed()
    }

    fn motion_busy(&self) -> bool {
        self.motion.busy(&self.settings)
    }

    fn motion_mode(&self) -> &'static str {
        self.motion.mode_name(&self.settings)
    }

    fn arm_pose(&self) -> (f32, f32) {
        let p = self.motion.pose(&self.settings);
        (p.theta_deg, p.r)
    }

    fn ap_mode(&self) -> bool {
        self.net.ap_mode()
    }
}

fn main() -> anyhow::Result<()> {
    esp_idf_svc::sys::link_patches();
    EspLogger::initialize_default();

    let p = Peripherals::take()?;
    let pins = p.pins;

    // Pump off before anything else.
    let ledc_timer = LedcTimerDriver::new(
        p.ledc.timer0,
        &TimerConfig::new().frequency(Hertz(5000)).resolution(Resolution::Bits10),
    )?;
    let pump = Pump::new(LedcDriver::new(p.ledc.channel0, ledc_timer, pins.gpio23)?);

    let button = PinDriver::input(pins.gpio13, Pull::Up)?;
    let mut led = PinDriver::output(pins.gpio2)?;

    if let Err(e) = storage::mount() {
        log::error!("LittleFS mount failed: {e}");
    }
    #[allow(unused_mut)]
    let mut settings = storage::load_settings();
    #[cfg(feature = "wokwi")]
    if settings.wifi_ssid.is_empty() {
        log::info!("Wokwi build: joining Wokwi-GUEST");
        settings.wifi_ssid = "Wokwi-GUEST".into();
    }
    // Wokwi builds put a short test recipe first, so a full brew fits a test run.
    #[cfg(feature = "wokwi")]
    storage::ensure_default_recipes(include_str!("../../wokwi/recipes.json"));
    #[cfg(not(feature = "wokwi"))]
    storage::ensure_default_recipes(web::DEFAULT_RECIPES_JSON);

    let pulses = PulseCounter::new(pins.gpio16)?;
    let thermo = Ds18b20::new(PinDriver::input_output_od(pins.gpio4, Pull::Floating)?, millis());

    let (theta, radial) = stepper::start(
        (pins.gpio26, pins.gpio25, settings.invert_theta),
        (pins.gpio33, pins.gpio32, settings.invert_radial),
    )?;
    let mut enable_pin = PinDriver::output(pins.gpio27)?;
    let enable: Enable = Box::new(move |on| {
        let _ = enable_pin.set_level((!on).into()); // active low
    });
    let motion = Motion::new(theta, radial, enable, &settings);
    let theta_endstop = PinDriver::input(pins.gpio18, Pull::Up)?;
    let radial_endstop = PinDriver::input(pins.gpio19, Pull::Up)?;

    let net = net::start(p.modem, EspSystemEventLoop::take()?, EspDefaultNvsPartition::take()?, &settings)?;
    #[cfg(feature = "wokwi")]
    log::info!(
        "Wokwi: open http://localhost:8180 (forwarded by the VS Code extension); openpour.local and the 10.13.37.x \
         address exist only inside the simulation"
    );

    let mut dev = Devices {
        settings,
        net,
        pulses,
        meter: FlowMeter::default(),
        thermo,
        pump,
        motion,
        theta_endstop,
        radial_endstop,
    };
    let mut brew = Brew::default();
    let mut trail = nozzle::Trail::default();
    let mut button_state = Button::default();
    let mut last_status_ms = 0u32;
    let mut reboot_at: Option<u32> = None;
    let mut last_loop_ms = millis();
    let mut last_stall_log_ms = 0u32;

    loop {
        let now = millis();
        let gap = now.wrapping_sub(last_loop_ms);
        last_loop_ms = now;
        if gap > LOOP_STALL_MS && now.wrapping_sub(last_stall_log_ms) >= 1000 {
            last_stall_log_ms = now;
            log::warn!(target: "loop", "main loop stalled {gap} ms");
        }
        dev.update(now);
        brew.update(&mut dev);
        trail.update(&dev);

        let mut effects = Vec::new();
        if let Some(press) = button_state.update(button.is_low(), now) {
            effects.extend(app::handle_press(press, &mut brew, &mut dev));
        }
        while let Some(line) = dev.net.pop_command() {
            effects.extend(app::handle_command(&line, &mut brew, &mut dev));
        }
        for fx in effects {
            match fx {
                Effect::Notify { kind, msg } => dev.net.send_event(Effect::notify_json(kind, &msg)),
                Effect::Reboot => reboot_at = Some(now.wrapping_add(REBOOT_DELAY_MS)),
            }
        }

        let _ = led.set_level(app::led_on(brew.state(), dev.net.ap_mode(), now).into());

        if dev.net.wants_status() || now.wrapping_sub(last_status_ms) >= STATUS_PERIOD_MS {
            last_status_ms = now;
            let mut status = brew.status(&dev);
            status["path"] = trail.take_json(now);
            dev.net.send_status(status.to_string());
        }
        if reboot_at.is_some_and(|t| now.wrapping_sub(t) as i32 >= 0) {
            reset::restart();
        }
        FreeRtos::delay_ms(1);
    }
}

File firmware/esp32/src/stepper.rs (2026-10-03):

//! Step generation for both axes from one 40 kHz hardware-timer interrupt.
//!
//! Each axis runs in velocity mode: the main loop sets a target speed, and
//! the interrupt ramps towards it at the axis's acceleration and emits steps
//! from a phase accumulator. Speeds are steps/s in 16.16 fixed point; the
//! interrupt does integer maths only (no FPU use in ISRs on the ESP32).
//!
//! The interrupt is not placed in IRAM, so steps pause while flash is being
//! written (saving settings or recipes). Positions stay exact; the control
//! loop catches up afterwards.

use core::ffi::c_void;
use core::ptr;
use core::sync::atomic::{AtomicBool, AtomicI32, AtomicU32, Ordering::*};

use esp_idf_svc::hal::delay::Ets;
use esp_idf_svc::hal::gpio::OutputPin;
use esp_idf_svc::sys::*;
use pourcore::motion::Axis;

const TICK_HZ: u32 = 40_000;
const TIMER_RES_HZ: u32 = 1_000_000;
/// At most one step per two ticks (high, then low).
const MAX_HZ: f32 = (TICK_HZ / 2) as f32;
const Q: f32 = 65536.0;
/// The phase accumulator wraps (one step) after TICK_HZ seconds' worth of
/// 16.16 speed: 40 000 << 16 fits in a u32 with room for one more tick.
const STEP_THRESHOLD: u32 = TICK_HZ << 16;

struct Channel {
    step_pin: AtomicI32,
    dir_pin: AtomicI32,
    invert: AtomicBool,
    pos: AtomicI32,
    /// Current speed, written only by the interrupt.
    v: AtomicI32,
    /// Requested speed.
    target: AtomicI32,
    /// Speed change per tick.
    accel: AtomicI32,
    phase: AtomicU32,
    pulse_high: AtomicBool,
    force: AtomicBool,
    force_pos: AtomicI32,
}

impl Channel {
    const fn new() -> Self {
        Channel {
            step_pin: AtomicI32::new(-1),
            dir_pin: AtomicI32::new(-1),
            invert: AtomicBool::new(false),
            pos: AtomicI32::new(0),
            v: AtomicI32::new(0),
            target: AtomicI32::new(0),
            accel: AtomicI32::new(1),
            phase: AtomicU32::new(0),
            pulse_high: AtomicBool::new(false),
            force: AtomicBool::new(false),
            force_pos: AtomicI32::new(0),
        }
    }

    #[inline(always)]
    fn tick(&self) {
        let step = self.step_pin.load(Relaxed);
        if step < 0 {
            return;
        }
        if self.pulse_high.load(Relaxed) {
            unsafe { gpio_set_level(step, 0) };
            self.pulse_high.store(false, Relaxed);
        }
        if self.force.load(Acquire) {
            self.v.store(0, Relaxed);
            self.target.store(0, Relaxed);
            self.phase.store(0, Relaxed);
            self.pos.store(self.force_pos.load(Relaxed), Relaxed);
            self.force.store(false, Release);
            return;
        }

        let target = self.target.load(Relaxed);
        let a = self.accel.load(Relaxed);
        let old = self.v.load(Relaxed);
        let v = if old < target {
            (old + a).min(target)
        } else {
            (old - a).max(target)
        };
        self.v.store(v, Relaxed);
        if v == 0 {
            return;
        }
        if v.signum() != old.signum() {
            // Direction changes: set DIR now, step no earlier than next tick.
            let forward = v > 0;
            let level = forward != self.invert.load(Relaxed);
            unsafe { gpio_set_level(self.dir_pin.load(Relaxed), level as u32) };
            self.phase.store(0, Relaxed);
            return;
        }
        // |v| <= MAX_HZ keeps this below 2 * STEP_THRESHOLD (no overflow).
        let mut ph = self.phase.load(Relaxed) + v.unsigned_abs();
        if ph >= STEP_THRESHOLD {
            ph -= STEP_THRESHOLD;
            unsafe { gpio_set_level(step, 1) };
            self.pulse_high.store(true, Relaxed);
            self.pos.fetch_add(v.signum(), Relaxed);
        }
        self.phase.store(ph, Relaxed);
    }
}

static CHANNELS: [Channel; 2] = [Channel::new(), Channel::new()];

unsafe extern "C" fn on_alarm(
    _timer: gptimer_handle_t,
    _event: *const gptimer_alarm_event_data_t,
    _ctx: *mut c_void,
) -> bool {
    for c in &CHANNELS {
        c.tick();
    }
    false // no task woken
}

fn output(pin: i32) -> Result<(), EspError> {
    esp!(unsafe { gpio_reset_pin(pin) })?;
    esp!(unsafe { gpio_set_direction(pin, gpio_mode_t_GPIO_MODE_OUTPUT) })?;
    esp!(unsafe { gpio_set_level(pin, 0) })
}

/// One axis's handle for the main loop.
pub struct Stepper {
    ch: &'static Channel,
}

impl Stepper {
    fn new(
        idx: usize,
        step: impl OutputPin,
        dir: impl OutputPin,
        invert: bool,
    ) -> Result<Stepper, EspError> {
        let ch = &CHANNELS[idx];
        let (step, dir) = (step.pin() as i32, dir.pin() as i32);
        output(step)?;
        output(dir)?;
        ch.invert.store(invert, Relaxed);
        ch.dir_pin.store(dir, Relaxed);
        ch.step_pin.store(step, Release);
        Ok(Stepper { ch })
    }
}

impl Axis for Stepper {
    fn position(&self) -> i32 {
        self.ch.pos.load(Relaxed)
    }

    fn is_running(&self) -> bool {
        self.ch.v.load(Relaxed) != 0 || self.ch.target.load(Relaxed) != 0
    }

    fn run_at(&mut self, hz: f32) {
        self.ch.target.store((hz.clamp(-MAX_HZ, MAX_HZ) * Q) as i32, Relaxed);
    }

    fn stop(&mut self) {
        self.ch.target.store(0, Relaxed);
    }

    fn force_stop_at(&mut self, position: i32) {
        self.ch.force_pos.store(position, Relaxed);
        self.ch.force.store(true, Release);
        // The interrupt applies it within one tick (25 µs).
        for _ in 0..1000 {
            if !self.ch.force.load(Acquire) {
                return;
            }
            Ets::delay_us(1);
        }
    }

    fn set_acceleration(&mut self, steps_per_s2: f32) {
        let per_tick = (steps_per_s2 * Q / TICK_HZ as f32) as i32;
        self.ch.accel.store(per_tick.max(1), Relaxed);
    }
}

/// Applies the direction settings. Takes effect at the next direction change,
/// so call it while the axes are stopped (as they are when settings change).
pub fn set_inverted(theta: bool, radial: bool) {
    CHANNELS[0].invert.store(theta, Relaxed);
    CHANNELS[1].invert.store(radial, Relaxed);
}
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

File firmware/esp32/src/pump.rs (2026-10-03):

//! 12 V pump on a low-side MOSFET module, 5 kHz PWM speed control.

use esp_idf_svc::hal::ledc::LedcDriver;

pub struct Pump<'d> {
    pwm: LedcDriver<'d>,
    duty: f32,
    stop_at_ms: Option<u32>,
}

impl<'d> Pump<'d> {
    pub fn new(pwm: LedcDriver<'d>) -> Self {
        let mut p = Pump { pwm, duty: 0.0, stop_at_ms: None };
        p.write(0.0);
        p
    }

    fn write(&mut self, d: f32) {
        self.duty = d.clamp(0.0, 1.0);
        let max = self.pwm.get_max_duty();
        let _ = self.pwm.set_duty((self.duty * max as f32 + 0.5) as u32);
    }

    /// Ends timed runs.
    pub fn update(&mut self, now: u32) {
        if self.stop_at_ms.is_some_and(|t| now.wrapping_sub(t) as i32 >= 0) {
            self.set(0.0);
        }
    }

    /// 0..1, cancels any timed run.
    pub fn set(&mut self, duty: f32) {
        self.stop_at_ms = None;
        self.write(duty);
    }

    pub fn run_for(&mut self, duty: f32, ms: u32, now: u32) {
        self.write(duty);
        self.stop_at_ms = Some(now.wrapping_add(ms));
    }

    pub fn duty(&self) -> f32 {
        self.duty
    }
}

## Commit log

2026-10-03 Add CAD and EUR prices to the bill of materials
    Each priced table gets ≈ CAD and ≈ EUR columns converted from the USD
    figures at 1 USD ≈ 1.42 CAD ≈ 0.89 EUR (October 2026). The totals in the
    BOM and README now show all three currencies.
2026-10-03 Port the firmware from C++/Arduino to Rust on ESP-IDF
    The firmware is now two crates under firmware/:
    - pourcore: everything that doesn't touch hardware. Kinematics, pour
    patterns and flow control are direct ports; the scale filter, settings,
    recipes, motion control, the brew state machine and command handling
    moved here too, behind Machine and Axis traits, so they are unit tested
    on the host (cargo test, 35 tests including simulated brews).
    - esp32: the hardware glue on esp-idf-svc. Steps for both axes come from
    a 40 kHz gptimer interrupt (replacing FastAccelStepper), with
    bit-banged HX711 and DS18B20 drivers, LEDC pump PWM, Wi-Fi with the
    same AP fallback at 192.168.4.1, mDN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
    [partitions.csv]
2026-10-04 docs: update for flow sensor shift
2026-10-04 feat: use flowmeter
    [config.scad, openpour.scad, parts.scad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]
2026-10-04 fix: log the distance homing travelled, not the axis position
    The radial endstop line printed the raw step position as "steps travelled".
    Record where homing started and report the travel in mm, which is what you
    check for a slipping belt.
2026-10-04 feat: add a host simulator that runs pourcore against simulated hardware
    firmware/sim runs the firmware's brew logic, flow controller, flow meter
    and motion controller on a PC, with stepper axes that home against real
    endstop switches, a pump with ripple and coast-down, and a flow meter whose
    true pulses per litre differs from the default. It serves the built web app
    and the firmware's /api and /ws protocol, plus /api/sim to inject faults
    (dry pump, dead meter, stuck endstops, missing probe) and read what really
    reached the cup.
    [hardware.rs, main.rs]
2026-10-04 fix: drop messages into an outbox to stop deadlocks
    [main.rs]
2026-10-04 feat: nozzle position api and functions
2026-10-04 feat: broadcast nozzle position
2026-10-04 feat: UI charts for nozzle positioning and flow rate
2026-10-05 feat: merge all for export.sh
    [openpour.scad]
2026-10-05 feat: export to stl script
2026-10-09 update bom
